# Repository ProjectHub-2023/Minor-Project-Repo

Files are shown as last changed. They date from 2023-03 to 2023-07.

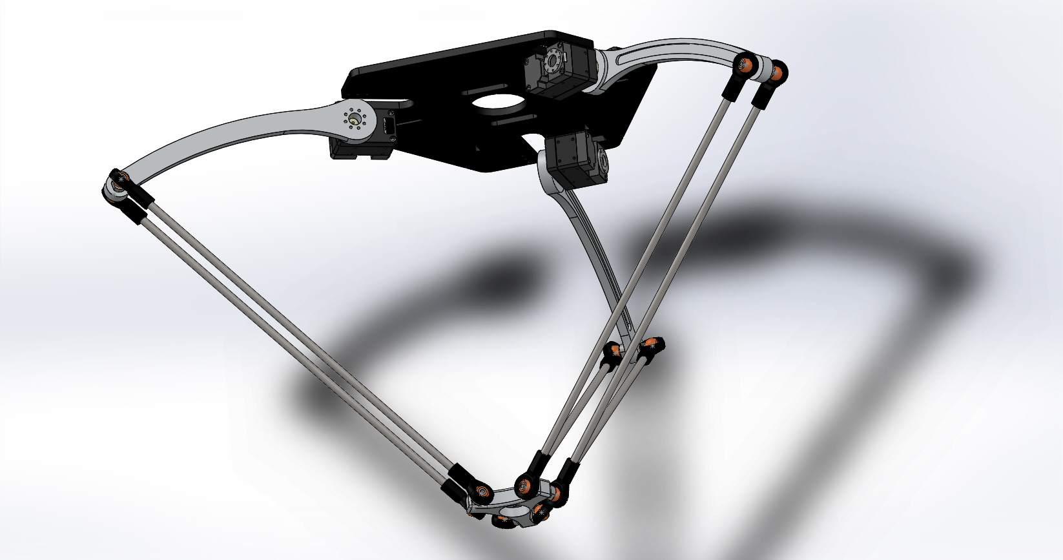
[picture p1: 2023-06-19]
3d_design/Mat_1.JPG

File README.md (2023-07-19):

# Quality Control of Products using 4-DOF Delta Robot

## Introduction

A Delta Robot is a type of parallel robotic manipulator known for its high-speed and precise motion capabilities. Unlike traditional serial robotic manipulators, which use a series of connected joints and links, Delta Robots employ a parallel mechanism with multiple arms connected to a common base. This design allows for greater agility, reduced inertia, and improved performance in high-speed applications, making them ideal for tasks that require rapid and accurate movements. The 4-DOF Delta Robot for Quality Control presented here harnesses these unique characteristics to carry out quality control operations efficiently.

## Problem Description
The problem is to develop a solution for pick and place operations in industrial settings using a delta robot. The objective is to create a system that can efficiently and accurately pick up objects from one location and place them in another, based on predefined parameters or instructions. The solution should be designed to handle various types of objects, sizes, and weights commonly found in industrial environments.

The system needs to be reliable, capable of operating for extended periods without significant downtime. It should also be versatile, allowing for easy adaptation to different production lines or processes. The solution should offer precise control and positioning, ensuring that objects are picked up and placed with high accuracy and repeatability.

Efficiency is a key requirement, as the solution should optimize the pick and place operations to minimize cycle times and increase overall productivity. It should be capable of handling a high volume of objects within a given time frame, while maintaining quality and safety standards.

Integration with existing manufacturing systems and equipment is crucial. The solution should be compatible with industry-standard protocols and interfaces, enabling seamless communication and coordination with other machinery or control systems. Additionally, the solution should be user-friendly, providing intuitive interfaces for operators to monitor and control the pick and place operations effectively.

## Problem Statement
Develop a Cost and Power-efficient 4-DOF Delta Robot which can be used for the inspection and quality control of QR Code Equipped Industrial packages by referring to required dimensions stored in the database model. The segregated packages need to be sent back for re-evaluation.
## Features and Capabilities
- 4 degrees of freedom (4-DOF)
- Precise and accurate performance for quality control operations
- Dimension-based item classification
- Payload capacity of 100 grams, allowing for versatility in handling different products

#### Capabilities
1. Autonomous Operation
 - Detecting the Product
 - Differentiate betweenfaulty and non-faulty
 - Determining the position of the product w.r.t the conveyer
 - Pick Product
 - Handle Product
 - Deliver Product
 - Intersystem Communication
 - Database Management
2. Safety
 - Pick Product Safely
 - Handle Product Safely
 - Place Product Safely
 - Facilitates emergency STOP feature
3. Standby Mode
4. Easy adaptability to newer environment
## Dependencies
1. **Book Reference:** "Practical Model-Based System Engineering" by Carlos Hernandez and Jose L. Fernandez. This book served as a valuable resource for adopting a systematic approach in our project. It guided us in identifying the project's needs and defining its capabilities. 
2. **MATLAB:** 
 - Simulink: The project utilizes Simulink, an extension of MATLAB, for system-level modeling and simulation of the Delta Robot's control system. Simulink diagrams are used to visualize the robot's behavior and test control strategies in a virtual environment.

 - Simscape: Simscape, a part of the MATLAB/Simulink ecosystem, is utilized to model the physical dynamics of the Delta Robot in a multi-domain simulation environment. It allows for the accurate representation of the robot's mechanical, electrical, and hydraulic components, enabling realistic simulation of the robot's motion and behavior.
 - System Composer: The project leverages System Composer, a powerful tool in the MATLAB/Simulink ecosystem, for modeling and analyzing the system architecture and requirements. System Composer helps us gain a comprehensive understanding of the Delta Robot's behavior, interactions between components, and supports our systematic approach to system engineering.
3. **SolidWorks:** A 3D computer-aided design (CAD) software used for mechanical and product design. SolidWorks was employed to create detailed models of the Delta Robot's physical components and analyze their mechanical behavior.
4. **Trossen Robotics Community Guide:** A valuable resource used for programming the Delta Robot. This guide provides essential information, code examples, and best practices for effectively controlling and integrating the Delta Robot into various applications.
5. Marginally Clever Rotary Delta Robot Forward/Inverse Kinematics Calculator
6. Proto G Engineering. “Simplified Delta Robot Kinematics Equations”, YouTube, Feb. 11, 2018[Video File]. Available: https://www.youtube.com/watch?v=FTRCwuAnr6o&t=57s&ab_channel=ProtoGEngineering
7. **Dynamixel Wizard 2.0:**  A software tool provided by Dynamixel for configuring and managing Dynamixel servos used in the Delta Robot. Dynamixel Wizard 2.0 allows for easy setup, calibration, and fine-tuning of the servos to achieve precise movements and control.

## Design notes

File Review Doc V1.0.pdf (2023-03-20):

# 1.Operational Scenarios:

Deployment or Adaptation Phase

1. System Configurations and calibrations
2. Configure the system according to the product being used.

Operation Phase

3. Product/item detected.
4. System Start.
5. Pick Product/item.
6. Translate the product/item.
7. Place the Product/item.
8. Return to home position.
9. Stand by.
10.Emergency Stop.

### 1.1 Description of Operational Scenarios

Deployment or Adaptation Phase | S1 System configuration and calibration
Preconditions | • The System should arrive at the destination of set up without any damages. • An empty space should be made available for the system set up. • The specified space should be a leveled surface. • The power supply should be available.
Triggering Event | The system should be bought by a customer.
Description | The system is bought by the customer and it is our duty to set up, configure and calibrate off-line for the customer.
Post-Conditions | The system is configured and calibrated.
Operational Scenario | S2 Configure new product
Preconditions | • The system should be well set up. • The system should be configured and calibrated. • The product to be sorted should be labelled with QR code
Triggering Event | Dimensional analysis of product.
Description | We add new products labelled with QR code, possibly of different sizes and configure the system with new products.
Post-Conditions | Now, the product is placed on the conveyor, and it can be detected by the system.

Operational Scenario | S3 Product/item Detected.
Preconditions | • The power supply should be available. • The robot should be configured and ready to use. • The product/item should be on the conveyor.
Triggering Event | The product placed on the conveyor is sensed and a signal is sent that the product has arrived.
Description | The product is detected and helps to activate the system.
Post-Conditions | • System is started.
Operational Scenario | S4 System Start.
Preconditions | • The power supply should be available. • The sensors should detect the product/item.
Triggering Event | Product/item is detected in the previous scenario.
Description | Initializes the operational parameters required to complete a single cycle process.
Post-Conditions | The QR code is scanned and is then matched with the prerequisite data available in the database.
Operational Scenario | S5 Pick Product/item.
Preconditions | • The product/item should be within reach of the delta robot. • The weight of the product should be within the range of the robot’s payload capacity. • The dimensions of the product shouldn’t be the same as those of the dimensions saved in the database.
Triggering Event | The dimensions of the product/item do not match the dimensions recorded in the database.
Description | In this process the Delta robot picks up the products/items which do not match the dimensions.
Post-Conditions | • The product/item is picked up by the end effector ready to be translated by the bot.
Operational Scenario | S6 Translate the product/item.
Preconditions | • The product/item should already be held by the grippers. • It needs to be ensured that the location where the product/item is to be relocated is empty/free.
Triggering Event | The defective product/item is detected and is already picked up by the Delta Robot.
Description | This is the stage in which the product/item is transported to another location (segregated) from the main production line.
Post-Conditions | • The translated product is ready to be placed.

Operational Scenario | S7 Place the Product/item.
Preconditions | • The product/item should already be translated to the desired place and ready to be placed.
Triggering Event | The Delta Robot has translated and reached the desired place where the defective piece can be placed/dropped.
Description | The Delta Robot has picked and translated (product/item) a certain distance from the main conveyer and is now ready to place the defective product/item on an empty surface.
Post-Conditions | • The defective product has now been segregated from the main conveyer. • The robot can then return to its home position.
Operational Scenario | S8 Return to home position.
Preconditions | • All the operations involved in the completion of a single process cycle must be completed. • Gripper should not have any product attached to it.
Triggering Event | Completion of a single operation cycle.
Description | This is the stage where the robot returns to its home position after completing one cycle of operation and is ready to execute the next.
Post-Conditions | • Robot returns to home position and proceeds to go in STANDBY state after a set duration.
Operational Scenario | S9 Stand by.
Preconditions | • There shouldn't be any products/items arriving on the conveyor for a certain duration of time. • Previous cycle should have been completed
Triggering Event | Set threshold time to go into standby mode is exceeded.
Description | The Home position is maintained.
Post-Conditions | The robot in standby mode is ready for actuation in case a product is detected.
Operational Scenario | S10 Emergency Stop.
Preconditions | • The system should be running.
Triggering Event | When the emergency switch is closed.
Description | In this scenario, irrespective of what process is running the whole system is forcefully turned off in real-time.
Post-Conditions | • The whole system operations are suspended. • The power supply to all the electrical components are cut-out.

### 1.2. Operational Needs from Operational Scenarios

S3 Product/item Detected:
- ON3_1: The system shall identify the product on the conveyor line and notify the subsequent processes about its arrival.
- ON3_2: The system shall be able to visually perceive and differentiate between a moving conveyor and an object on a moving conveyor.
- ON3_3: The response time must be instantaneous or as minimal as possible.
- ON3_4:

S4 System Start:
- ON4_1: The system shall indicate the beginning of the operation.
- ON4_2: The system shall transmit activation signals to all its subsystems.
- ON4_3: The system status shall be logged into the database for diagnostics in case of any contingency.
- ON4_4:

S5 Pick Product/item:
- ON5_1: The system shall be able to pick products of cylinder or box shape, with a maximum dimension of 5 cm^3 and a minimum dimension of 0.5 cm³
and a maximum
weight of 100 g.
- ON5_2: The system shall complete the pick task in less than 2 seconds. if there are no potential collisions while performing.
- ON5_3: The system shall pick the item safely as per ISO 14539:2000.
- ON5_4: The moving parts of the system shall not present any sharp edges,
and the robot arm and the gripper to handle the parts shall be lightweight.

S6 Translate the product/item:
- ON6_1: The system shall change its position and orientation without dropping/damaging the product in the gripper.
- ON6_2: The system shall translate to the required location with minimal deviation.
- ON6_3: The system shall finish the repositioning in under 2 seconds.
- ON6_4:

S7 Place the Product/item:
- ON7_1: The system shall place the products in the desired location (whether it’s a conveyor or box)
- ON7_2: The system shall place the product with not more than 0.05 mm of clearance between the product and the surface.
- ON7_3: The system shall ensure that the release of the gripper and the product being placed on the surface are nearly simultaneous.
- ON7_4: The system shall ensure that the entire operation takes not more than 1.5 seconds to complete and move on to the subsequent process.
- ON7_5: The system shall place the item safely as per ISO 14539:2000.

S8 Return to home position:
- ON8_1: The system shall return all actuators and the end effector back to a certain predetermined configuration (home configuration).
- ON8_2: The system shall ensure that no product is currently being held by the gripper, unless the emergency STOP function has been engaged.
- ON8_3:
- ON8_4:

S9 Stand by:
- ON9_1: The system shall hold the relative positioning and orientation of the actuators and the end effector in the predetermined ‘Home’ configuration unless indicated otherwise by any other process.
- ON9_2: the system shall release the actuators and end effector from the home configuration when an appropriate trigger event occurs in the system (i.e., a faulty product is identified on the main conveyor).
- ON9_3: The transition of actuator states from ‘home’ configuration to the required configuration shall happen almost instantaneously and shall not take more than 2 seconds.
- ON9_4:

S10 Emergency Stop:
- ON10_1: The system shall terminate all currently ongoing operations.
- ON10_2: The actuators and the end effector shall halt their current actuation processes and hold their current position and orientation so as to not cause further damage.
- ON10_3: The state of the system shall be logged into the system as well as indicated to the operator.
- ON10_4: There shall be minimal delay between the trigger input and the triggering of the appropriate response. This shall not take more than 1 second.

## 2. UML Charts

### 2.1. Use Case Diagram

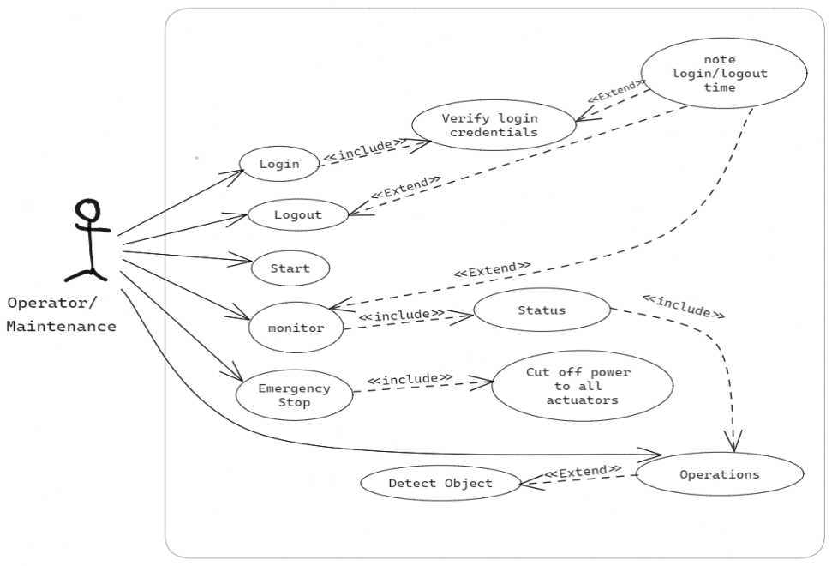
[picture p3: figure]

### 2.2. Sequence Diagram

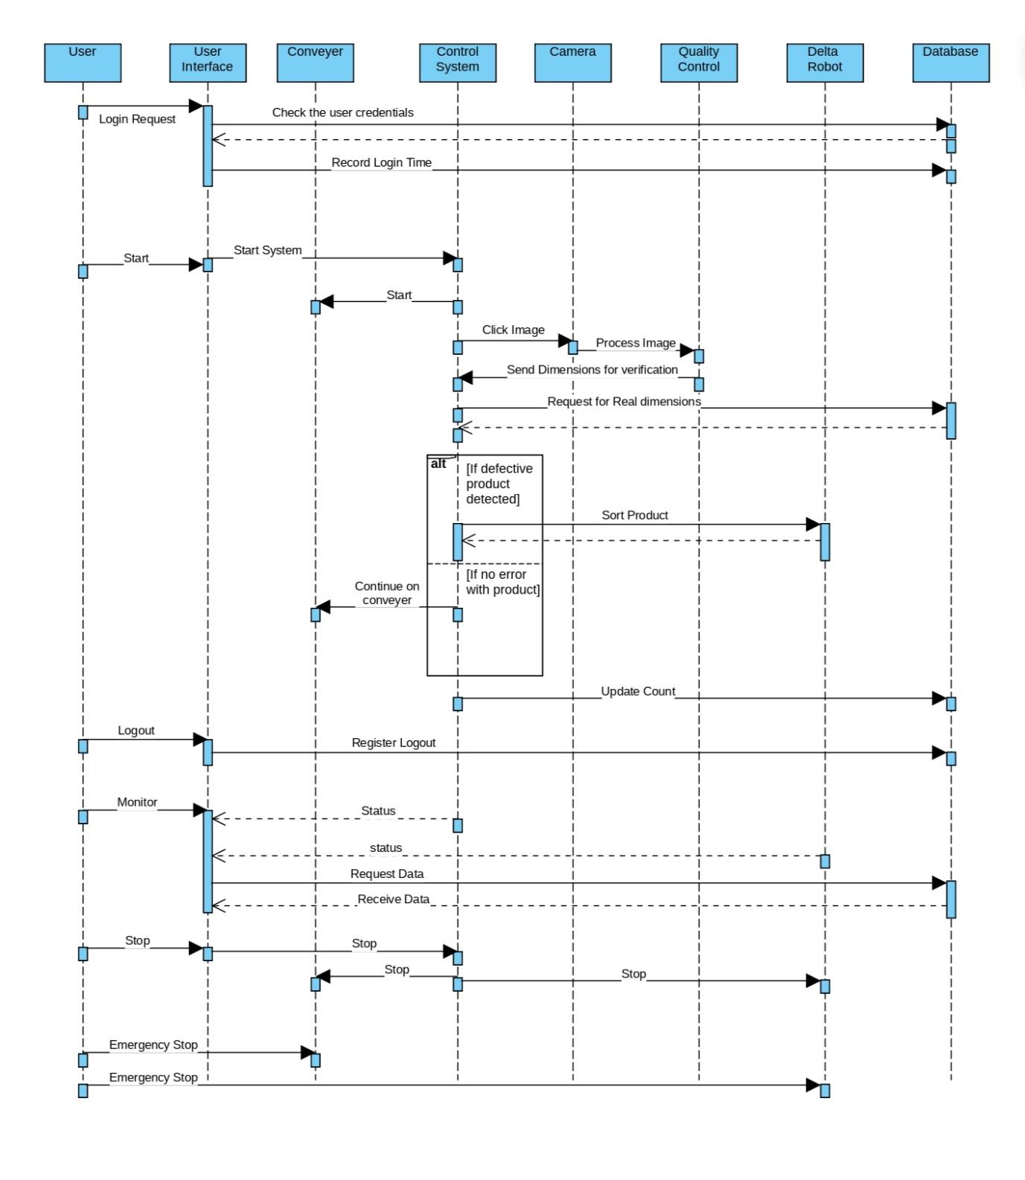
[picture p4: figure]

## 3. Capabilities

### 3.1. sysML Chart

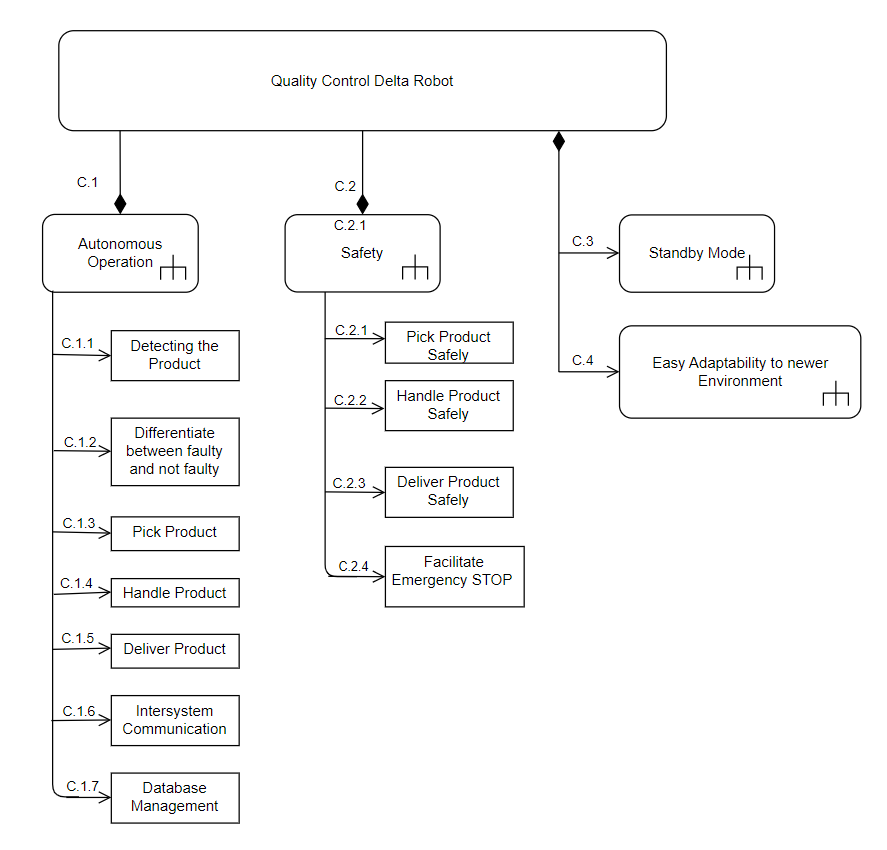
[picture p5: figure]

### 3.2. Capabilities

Capability | Description
C.1 Autonomous Operation | The robotic system should be able to identify and segregate faulty products from an ongoing production line autonomously.
C.1.1 Detecting the Product | The system should be able to detect the arrival of a product on a conveyer.
C.1.2 Differentiate between faulty and non-faulty | The system should be able to tell apart a faulty product from a conveyer line.
C.1.3 Determining the position of the product w.r.t the conveyer | The system should be able to determine the position of the product on the conveyer.

C.1.4 Pick Product | The robot can pick a product from the conveyer.
C.1.5 Handle Product | The robot can move holding any product without dropping it.
C.1.6 Deliver Product | The robot can deliver the products by placing them on to the desired location.
C.1.7 Intersystem Communication | The system should be able to communicate between the various subsystems so as to allow synchronization of processes.
C.1.8 Database Management | The system should have the ability to read, write and manipulate the database, whenever the need may arise.
C.2 Safety | The system and all its constituent subsystems must not cause harm to its surroundings with a priority to not cause any casualties to the operator.
C.2.1 Pick Product Safely | The robot picks the product while avoiding undesired collisions with any part of the product.
C.2.2 Handle Product Safely | The robot moves holding a product without losing grip on it or colliding with any obstacles.
C.2.3 Place Product Safely | The robot places the products in the desired location without inflicting any damage to the product.
C.2.4 Facilitates emergency STOP feature | In case of emergency, when indicated by the operator the system must terminate all operations instantaneously.
C.3 Standby Mode | After Initialisation or completion of an operation cycle, the system should have the ability to HOLD its position and wait for an appropriate trigger to begin operation.
C.4 Easy adaptability to newer environment | The system must be versatile enough to accommodate any work environment and operate optimally.

### 3.3 Traceability Matrix

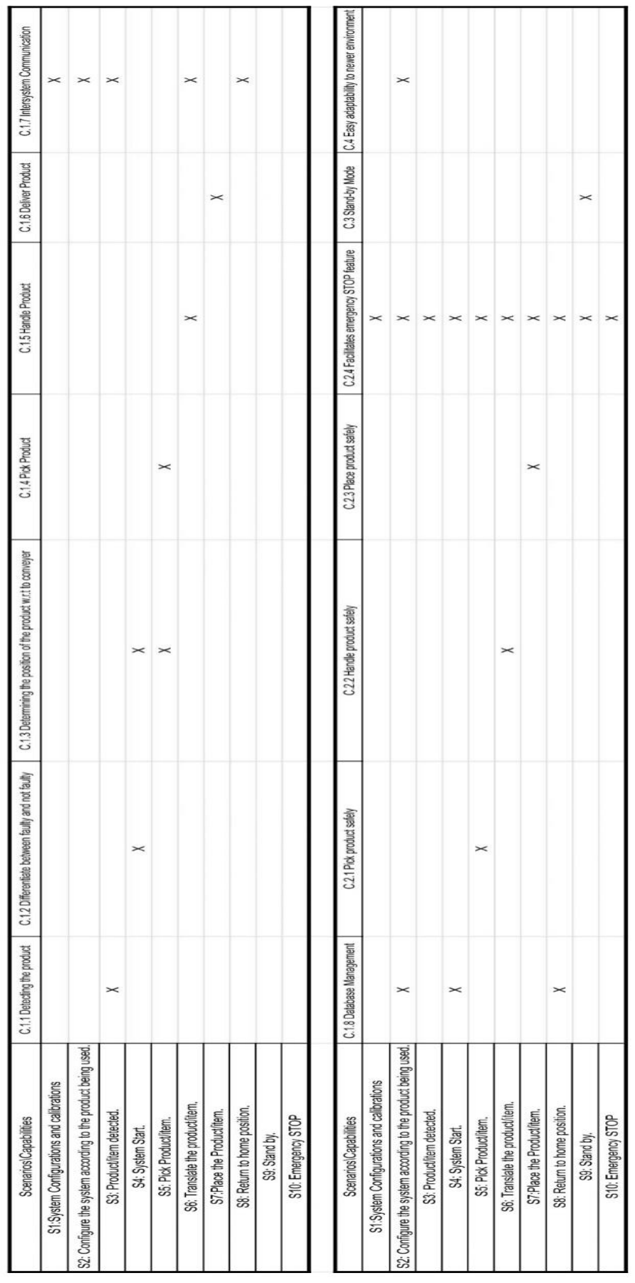
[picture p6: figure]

### 3.4 High Level Functions

High level Functions | Description
Manage Operation (From C1.1, C1.2, C3) | The system plans and executes the required operation based on the product categorisation.
Calibrate (from C4) | The system must be able to operate and adjust to different environments
Pick Product (from C1.4, C2.1, C2.2) | The system must pick the product in a safe manner without damaging the product.
Translate robot (from C2.2) | The system should translate the product without colliding with its operator or immediate environment.
Place Product (from C1.6, C2.2, C2.3) | The system places the product to the required location.
Handle Contingencies (from C2.4) | The system must stop all operations immediately when indicated by the user.

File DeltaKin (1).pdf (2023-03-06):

## The Delta Parallel Robot: Kinematics Solutions Robert L. Williams II, Ph.D., williar4@ohio.edu Mechanical Engineering, Ohio University, October 2016

Clavel’s Delta Robot¹
is arguably the most successful commercial parallel robot to date. The left image below shows the original design from Clavel’s U.S. patent² , and the right photograph below shows one commercial instantiation of the Delta Robot.

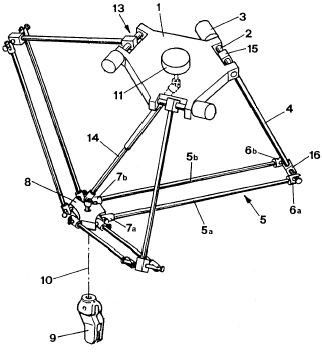
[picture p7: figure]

Delta Robot Design¹

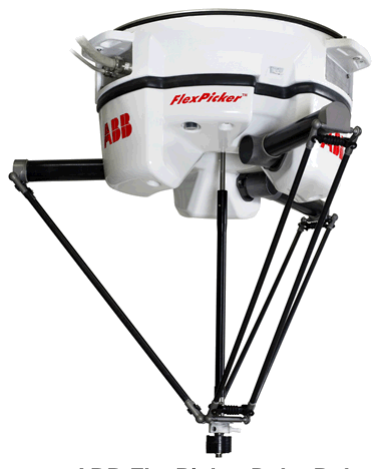
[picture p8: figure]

ABB FlexPicker Delta Robot www.abb.com

The Delta Robot has 4-degrees-of-freedom (dof), 3-dof for XYZ translation, plus a fourth inner leg to control a single rotational freedom at the end-effector platform (about the axis perpendicular to the platform). The remainder of this document will focus only on the 3-dof XYZ translation-only Delta Robot since that is being widely applied by 3D printers and Arduino hobbyists.

Presented is a description of the 3-dof Delta Robot, followed by kinematics analysis including analytical solutions for the inverse position kinematics problem and the forward position kinematics problem, and then examples for both, snapshots and trajectories. The velocity equations are also derived This is presented for both revolute-input and prismatic-input Delta Robots.

For referencing this document, please use:
R.L. Williams II, “The Delta Parallel Robot: Kinematics Solutions”, Internet Publication, www.ohio.edu/people/williar4/html/pdf/DeltaKin.pdf, January 2016.

1
R. Clavel, 1991, “Conception d'un robot parallèle rapide à 4 degrés de liberté”, Ph.D. Thesis, EPFL, Lausanne, Switzerland.
R. Clavel, 1990, “Device for the Movement and Positioning of an Element in Space”, U.S. Patent No. 4,976,582.

## Table of Contents

## Revolute-Input Delta Robot

Revolute-Input Delta Robot Description

As shown below, the 3-dof Delta Robot is composed of three identical RUU legs in parallel between the top fixed base and the bottom moving end-effector platform. The top revolute joints are actuated (indicated by the underbar) via base-fixed rotational actuators. Their control variables are
, | 1,2,3 i θ i = | about the axes shown. In this model θi are measured with the right hand, with zero angle
defined as when the actuated link is in the horizontal plane. The parallelogram 4-bar mechanisms of the three lower links ensure the translation-only motion. The universal (U) joints are implemented using three non-collocated revolute (R) joints (two parallel and one perpendicular, six places) as shown below.

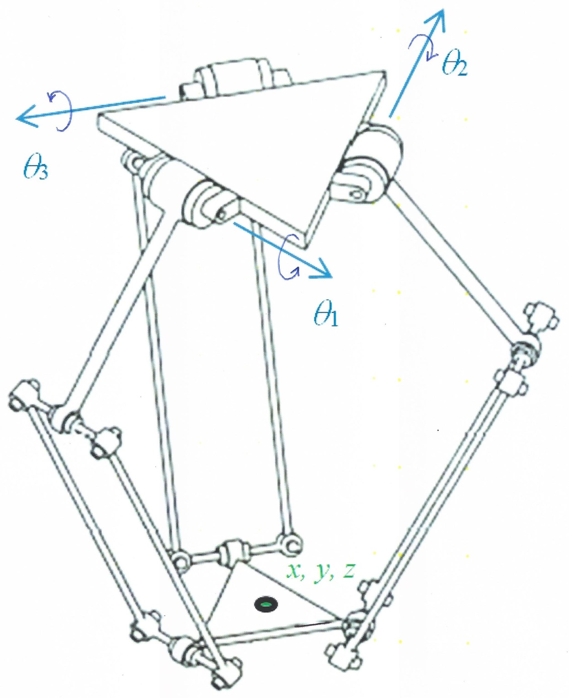
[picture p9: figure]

Delta Parallel Robot Diagram adapted from: elmomc.com/capabilities

The three-dof Delta Robot is capable of XYZ translational control of its moving platform within
its workspace. Viewing the three identical RUU chains as legs, points , | 1,2,3 Bi i | = | are the hips, points
, | 1,2,3 Ai i | = | are the knees, and points , | 1,2,3 Pi i | = | are the ankles. The side length of the base
equilateral triangle is sB and the side length of the moving platform equilateral triangle is sP. The moving platform equilateral triangle is inverted with respect to the base equilateral triangle as shown, in a constant orientation.

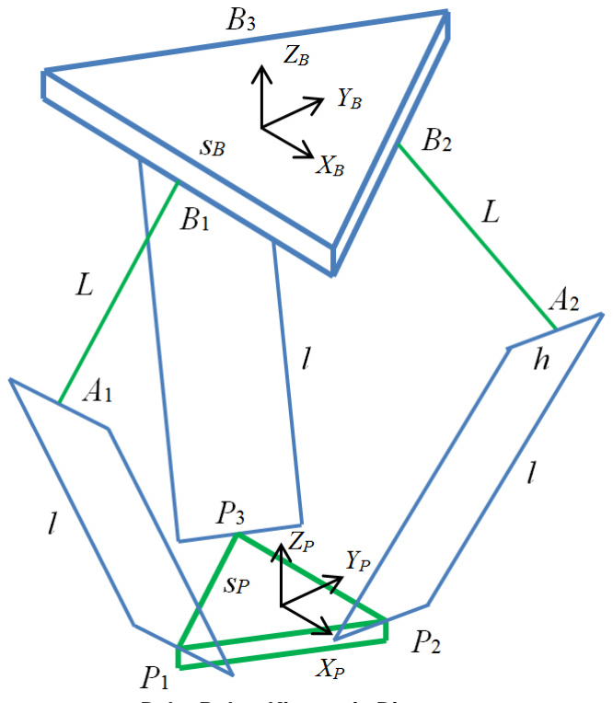
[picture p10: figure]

Delta Robot Kinematic Diagram

The fixed base Cartesian reference frame is {B}, whose origin is located in the center of the base equilateral triangle. The moving platform Cartesian reference frame is {P}, whose origin is located in the center of the platform equilateral triangle. The orientation of {P} is always identical to the orientation of {B} so rotation matrix 3

B

PRI = is constant. The joint variables are | { 1 | 2 | 3}
T

### Θ= θ θθ , and

the Cartesian variables are | { | } B | T
P P = x yz . The design shown has high symmetry, with three upper leg lengths L and three lower lengths l (the parallelogram four-bar mechanisms major lengths).

The Delta Robot fixed base and platform geometric details are shown on the next page.

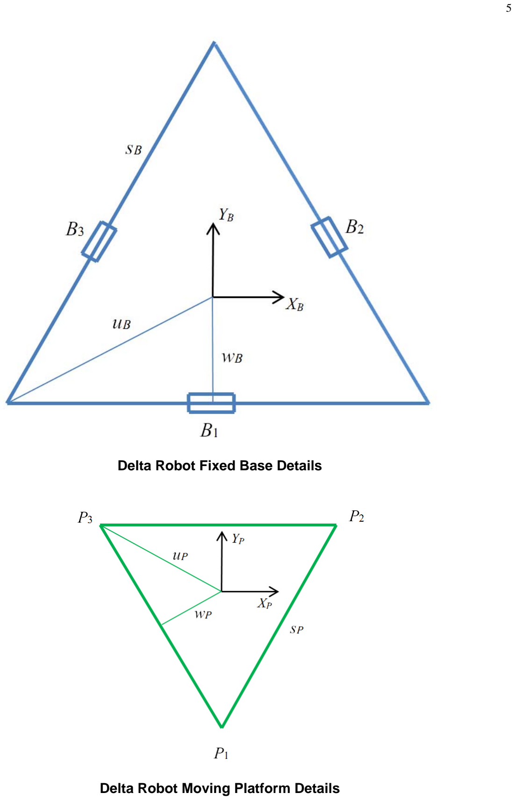
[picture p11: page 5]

Delta Robot Fixed Base Details

Delta Robot Moving Platform Details

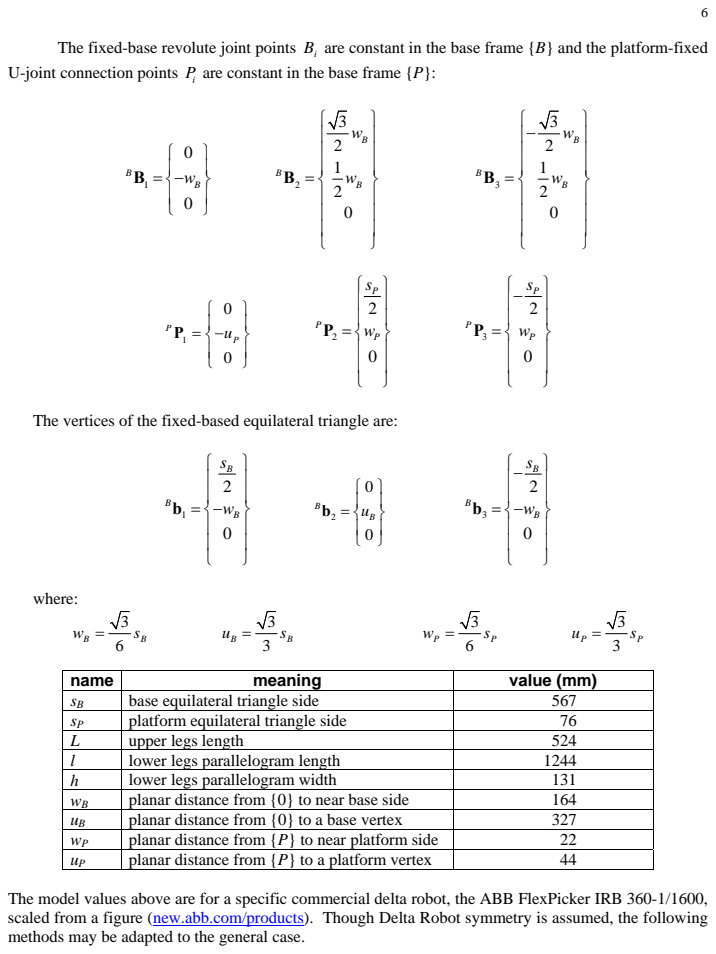
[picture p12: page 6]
where:

The fixed-base revolute joint points Bi are constant in the base frame {B} and the platform-fixed
U-joint connection points Pi are constant in the base frame {P}:

The vertices of the fixed-based equilateral triangle are:

name | meaning | value (mm)
sB | base equilateral triangle side | 567
sP | platform equilateral triangle side | 76
L | upper legs length | 524
l | lower legs parallelogram length | 1244
h | lower legs parallelogram width | 131
wB | planar distance from {0} to near base side | 164
uB | planar distance from {0} to a base vertex | 327
wP | planar distance from {P} to near platform side | 22
uP | planar distance from {P} to a platform vertex | 44

The model values above are for a specific commercial delta robot, the ABB FlexPicker IRB 360-1/1600,
scaled from a figure (new.abb.com/products). Though Delta Robot symmetry is assumed, the following
methods may be adapted to the general case.

Revolute-Input Delta Robot Mobility

This section proves that the mobility (the number of degrees-of-freedom) for the Delta robot is indeed 3-dof. Using the spatial Kutzbach mobility equation for the previous Delta Robot figure:

1 | 2 | 3 M = 6( | 1) 5 | 4 | 3 N | J | J | J -- | - | -

where:
M is the mobility, or number of degrees-of-freedom N is the total number of links, including ground
J1 is the number of one-dof joints
J2 is the number of two-dof joints
J3 is the number of three-dof joints

J1 – one-dof joints: revolute and prismatic joints J2 – two-dof joints: universal joint
J3 – three-dof joints: spherical joint

For the as-designed Delta Robot, we have:

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
6(17 1) 5(21) 4(0) 3(0)
9 dof

M
M
= | -- | - | -
=-

As often happens, the Kutzbach equation fails because the result must obviously be 3-dof. This result predicts the Delta is a severely overconstrained statically indeterminate structure, which is incorrect. The Kutzbach equation knows nothing about special geometry – in the Delta Robot case, there are three parallel four-bar mechanisms. The overall robot would work kinematically identically to the original Delta Robot if we removed one of the long parallel four-bar mechanism links, along with two revolute joints each. With this equivalent case, the Kutzbach equation yields:

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
6(14 1) 5(15) 4(0) 3(0)
3 dof

M
M
= | -- | - | -
=

which is correct. An alternative approach to calculating the Delta Robot mobility is by ignoring the three parallel four-bar mechanisms, replacing each with a single link instead. In this we must count a universal joint at either end of this virtual link. This approach follows the simplified Delta Robot naming convention 3-RUU. The Kutzbach equation for this case also succeeds:

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
6(8 1) 5(3) 4(6) 3(0)
3 dof

M
M
= | -- | - | -
=

Either of the second two approaches works. The author prefers the former since it is closer to the actual Delta Robot design.

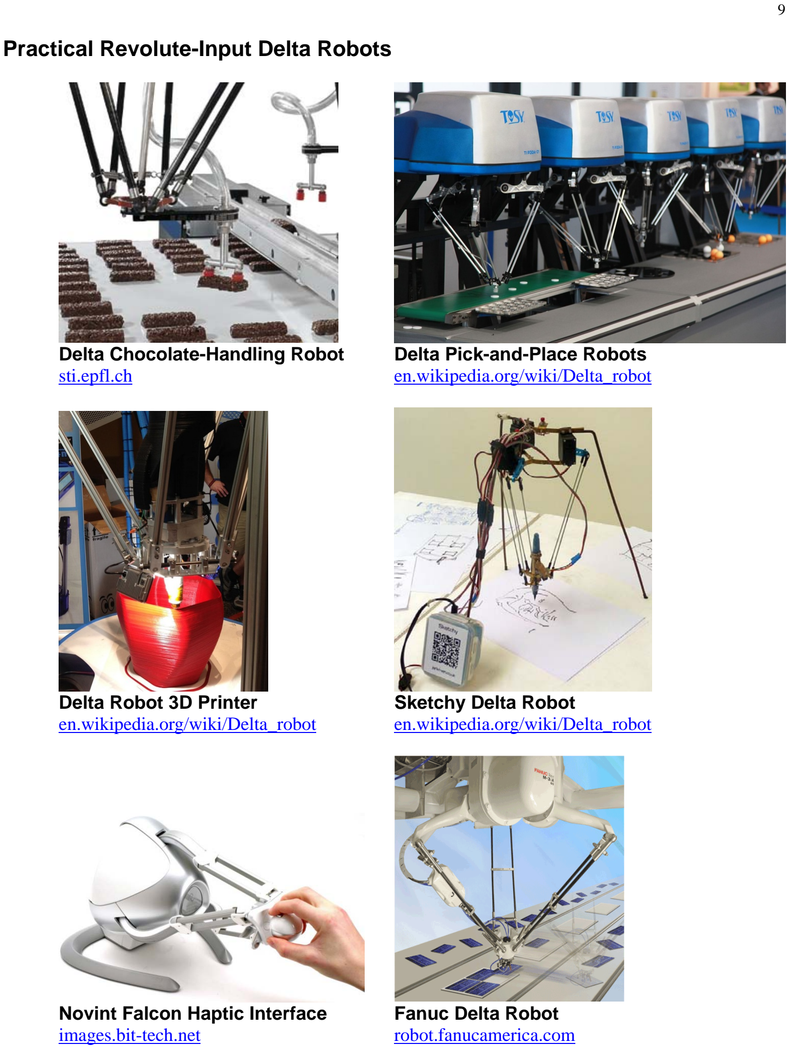
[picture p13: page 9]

Practical Revolute-Input Delta Robots

Delta Chocolate-Handling Robot | Delta Pick-and-Place Robots
sti.epfl.ch | en.wikipedia.org/wiki/Delta_robot
Delta Robot 3D Printer | Sketchy Delta Robot
en.wikipedia.org/wiki/Delta_robot | en.wikipedia.org/wiki/Delta_robot
Novint Falcon Haptic Interface | Fanuc Delta Robot
images.bit-tech.net | robot.fanucamerica.com

Revolute-Input Delta Robot Kinematics Analysis

From the kinematic diagram above, the following three vector-loop closure equations are written for the Delta Robot:
{ } { } { } { } | { } { } { } B | B | B | B | B | P | B | P
i | i | i | P | P | i | P | i + | + | = | + | = | + é | ù ë | û B | L | l | P | R | P | P | P | i =1,2,3
where | [ 3 ] B
P é | ù = ë | û R | I since no rotations are allowed by the Delta Robot.
The three applicable constraints state that the lower leg lengths must have the correct, constant length l (the virtual length through the center of each parallelogram):
{ } | { } { } { } { } B | B | P | B | B
i | i | P | i | i | i l = | = | + | - | - l | P | P | B | L | i =1,2,3

It will be more convenient to square both sides of the constraint equations above to avoid the square-root in the Euclidean norms:

{ } ² ² | 2 | 2 | 2 B
i | i | ix | iy | iz l | l | l | l = | =++ l | i =1,2,3
Again, the Cartesian variables are | { | } B | T
P P = x yz . The constant vector values for points Pi
and Bi | were given previously. | The vectors { } BLi | are dependent on the joint variables
{ 1 | 2 | 3}
T

### Θ= θ θθ :

1 | 1
| 1

0
cos
sin
B | L
L

θ
θ
ì | ü ï | ï =-í | ý
ï | ï î | þ -

L

2

2 | 2
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
ì | ü ï | ï ï | ï ï | ï = í | ý ï | ï ï - | ï ï | ï î | þ

L

3

3 | 3
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
ì | ü ï- | ï ï | ï ï | ï = í | ý ï | ï ï - | ï ï | ï î | þ

L

Substituting all above values into the vector-loop closure equations yields:

{}1 | 1

1

cos
sin

B

x
y L | a
zL

θ
θ
ì | ü ï | ï = | + | + í | ý
ï | ï î | þ +
l | {}

2

2 | 2
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
x | L | b
y | L | c
| zL

θ

θ
θ
ì | ü ï - | + ï ï | ï ï | ï = | - | + í | ý ï | ï ï | + | ï ï | ï î | þ
l | {}

3

3 | 3
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
x | L | b
y | L | c
| zL

θ

θ
θ
ì | ü
ï | ï + | -
= | - | + í | ý
ï | ï
+
î | þ

l

where: | 3
2 | 2
| 1
| 2
B | P

P
B
P | B

aw u
s b | w
cw | w
= | -

=-

= -

And the three constraint equations yield the kinematics equations for the Delta Robot:

2 | 2 | 2 | 2 | 2 | 2
1 | 1
2 | 2 | 2 | 2 | 2 | 2 | 2
2 | 2
2 | 2 | 2 | 2 | 2 | 2 | 2
3 | 3
2 ( | ) cos | 2 sin | 2 | 0
( 3( | ) | )cos | 2 sin | 2 | 2 | 0
( 3( | ) | )cos | 2 sin | 2 | 2 | 0
L y a | zL | x | y | z | a | L | ya l
L | x b | y c | zL | x | y | z | b | c | L | xb | yc l
L | x b | y c | zL | x | y | z | b | c | L | xb | yc l
θ | θ
θ | θ
θ | θ
+ | + | + + + + + + | -=
- | + ++ | + | + + + + + + + | + | - =
- -- | + | + + + + + + - | + | - =
The three absolute vector knee points are found using B | B | B A | B | L i | i | i = | + | , i =1,2,3:
1 | 1
| 1

0
cos
sin
B | wL B
L

θ
θ
ì | ü ï | ï =- - í | ý
ï | ï î | þ -

A

2

2 | 2

2

3 ( | cos ) 2
1 ( | cos )
2
sin

B

B
B
w | L
w | L

L

θ

θ
θ
ì | ü ï | + | ï ï | ï ï | ï = | + í | ý ï | ï ï | - | ï ï | ï î | þ

A

3

3 | 3

3

3 ( | cos ) 2
1 ( | cos )
2
sin

B

B
B
w | L
w | L

L

θ

θ
θ
ì | | ü
ï | ï - | +
= | + í | ý
ï | ï -
î | | þ

A

Inverse Position Kinematics (IPK) Solution

The 3-dof Delta Robot inverse position kinematics (IPK) problem is stated: Given the Cartesian
position of the moving platform control point (the origin of {P}), | { | } B | T
P P = x yz , calculate the three
required actuated revolute joint angles | { 1 | 2 | 3}
T
Θ= θ θθ . The IPK solution for parallel robots is often straightforward; the IPK solution for the Delta Robot is not trivial, but can be found analytically. Referring to the Delta Robot kinematic diagram above, the IPK problem can be solved independently for each of the three RUU legs. Geometrically, each leg IPK solution is the intersection between a known circle (radius L, centered on the base triangle R joint point B
Bi) and a known sphere (radius l, centered on the moving platform vertex P
Pi).

This solution may be done geometrically/trigonometrically. However, we will now accomplish this IPK solution analytically, using the three constraint equations applied to the vector loop-closure equations (derived previously). The three independent scalar IPK equations are of the form:

cos | sin | 0 E | F | G i | i | i | i | i θ + | += θ | i =1,2,3

where:

1

1
2 | 2 | 2 | 2 | 2 | 2
1

2( )
2
2
E | | Ly a
F | zL
G | x | y | z | a | L | ya l
= | +
=
=+++++ -

2

2
2 | 2 | 2 | 2 | 2 | 2 | 2
2
( 3( | ) | )
2
2( | )
E | L | xb | yc
F | zL
G | x | y | z | b | c | L | xb yc l
=- | + + +
=
= + +++++ | + | -

3

3
2 | 2 | 2 | 2 | 2 | 2 | 2
3
( 3( | ) | )
2
2( | )
E | L | xb yc
F | zL
G | x | y | z b c | L | xb yc l
= | - --
=
= + + + + + +- + | -
The equation | cos | sin | 0 E | F | G i | i | i | i | i θ + | += θ | appears a lot in robot and mechanism kinematics and is readily
solved using the Tangent Half-Angle Substitution.

If we define tan
2

i
i t
θ = | then

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
θ | - = +
and | 2

2 sin
1

i
i
i

t
t

θ = +

Substitute the Tangent Half-Angle Substitution into the EFG equation: 2

2 | 2
1 | 2 | 0
1 | 1
i | i
i | i | i
i | i
t | t E | F | G
t | t
æ | ö | æ | ö - ç | ÷ | ç | ÷ + | +=
è | ø | è | ø + | + | 2 | 2 (1 | ) | (2 ) | (1 | ) 0 E | t | Ft | G | t i | i | i | i | i | i - + | + | +=
2 ( | ) | (2 ) | ( | ) 0 G Et | Ft | G E i | ii | ii | i | i - | + | + | + | = | quadratic formula: 1,2
2 | 2 | 2
i | i | i | i
i
i | i
F | E | F | G
t
GE
-± | + | - = | -

Solve for θi by inverting the original Tangent Half-Angle Substitution definition:

1 2tan ( ) i | i θ | t - =

Two θi solutions result from the ± in the quadratic formula. Both are correct since there are two valid solutions – knee left and knee right. This yields two IPK branch solutions for each leg of the Delta Robot, for a total of 8 possible valid solutions. Generally the one solution with all knees kinked out instead of in will be chosen.

Forward Position Kinematics (FPK) Solution

The 3-dof Delta Robot forward position kinematics (FPK) problem is stated: Given the three
actuated joint angles | { 1 | 2 | 3}
T
Θ= θ θθ , calculate the resulting Cartesian position of the moving platform
control point (the origin of {P}), | { | } B | T
P P = x yz . The FPK solution for parallel robots is generally very difficult. It requires the solution of multiple coupled nonlinear algebraic equations, from the three constraint equations applied to the vector loop-closure equations (derived previously). Multiple valid solutions generally result.

Thanks to the translation-only motion of the 3-dof Delta Robot, there is a straightforward
analytical solution for which the correct solution set is easily chosen. Since | { 1 | 2 | 3}
T
Θ= θ θθ are given,
we calculate the three absolute vector knee points using B | B | B A | B | L i | i | i = | + | , i =1,2,3. Referring to the
Delta Robot FPK diagram below, since we know that the moving platform orientation is constant,
always horizontal with | [ 3 ] B
P éù = ëû R | I , we define three virtual sphere centers B | B | P A | A | P iv | i | i = | - , i =1,2,3:
1 | 1
| 1

0
cos
sin

B
v | B | P wL | u
L

θ
θ
ì | ü ï | ï =- - | + í | ý
ï | ï î | þ -

A

2

2 | 2
| 2
3 ( | cos ) 2 | 2
1 ( | cos )
2
sin

P
B

B
v | B | P

s wL

wL | w

L

θ

θ
θ
ì | ü
ï | ï + | -
= | + | - í | ý
ï | ï -
î | þ

A

3

3 | 3
| 3
3 ( | cos ) 2 | 2
1 ( | cos )
2
sin

P
B

B
v | B | P

s wL

wL | w

L

θ

θ
θ
ì | ü ï- | + | + ï ï | ï ï | ï = | + | - í | ý ï | ï ï | - | ï ï | ï î | þ

A

and then the Delta Robot FPK solution is the intersection point of three known spheres. Let a sphere be referred as a vector center point {c} and scalar radius r, ({c}, r). Therefore, the FPK unknown point
{ } B PP | is the intersection of the three known spheres:
({ 1 } BA v , l) | ({ 2 } B
A v , l) | ({ 3 } B
A v , l).

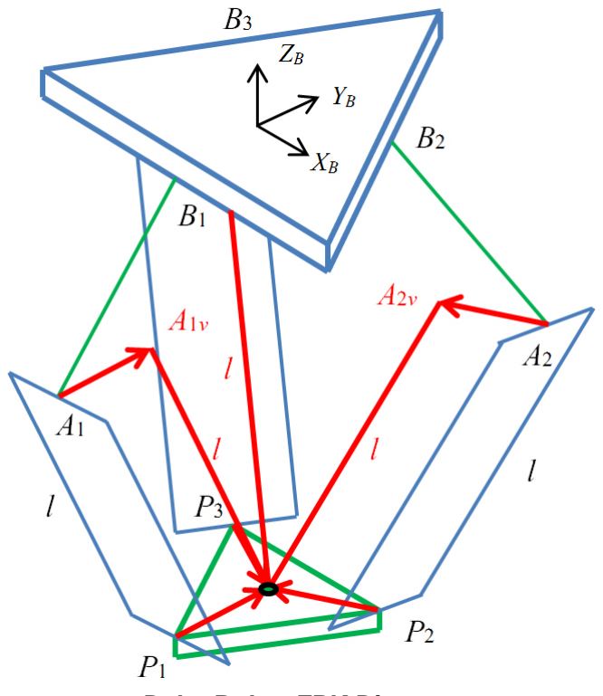
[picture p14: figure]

Delta Robot FPK Diagram

Appendix A presents an analytical solution for the intersection point of the three given spheres, from Williams et al.³
This solution also requires the solving of coupled transcendental equations. The appendix presents the equations and analytical solution methods, and then discusses imaginary solutions, singularities, and multiple solutions that can plague the algorithm, but all turn out to be no problem in this design.

In particular, with this existing three-spheres-intersection algorithm, if all three given sphere centers { } BAiv have the same Z height (a common case for the Delta Robot), there will be an

algorithmic singularity preventing a successful solution (dividing by zero). One way to fix this problem is to simple rotate coordinates so all { } BAiv Z values are no longer the same, taking care to reverse this

coordinate transformation after the solution is accomplished. However, we present another solution (Appendix B) for the intersection of three spheres assuming that all three sphere Z heights are identical, to be used in place of the primary solution when necessary.

Another applicable problem to be addressed is that the intersection of three spheres yields two solutions in general (only one solution if the spheres meet tangentially, and zero solutions if the center distance is too great for the given sphere radii l – in this latter case the solution is imaginary and the input data is not consistent with Delta Robot assembly). The spheres-intersection algorithm calculates both solution sets and it is possible to automatically make the computer choose the correct solution by ensuring it is below the base triangle rather than above it.

This three-spheres-intersection approach to the FPK for the Delta Robot yields results identical
to solving the three kinematics equations for | { | } B | T
P P = x yz given | { 1 | 2 | 3}
T
Θ= θ θθ .

3 R.L. Williams II, J.S. Albus, and R.V. Bostelman, 2004, “3D Cable-Based Cartesian Metrology System”, Journal of Robotic Systems, 21(5): 237-257.

Revolute-Input Delta Robot Velocity Kinematics Equations

The revolute-input Delta Robot velocity kinematics equations come from the first time derivative of the three position constraint equations presented earlier:

1 | 1 | 1 | 1 | 1 | 1
2 | 2 | 2 | 2 | 2 | 2
3 | 3 | 3 | 3
2 cos | 2 ( | ) sin | 2 sin | 2 | cos | 2 | 2( | ) | 2 | 0
( 3 | )cos | ( 3( | ) | ) sin | 2 sin | 2 | cos | 2( | ) | 2( | ) | 2 | 0
( 3 | )cos | ( 3( | ) | ) sin | 2 sin | 2
Ly | L y a | Lz | Lz | xx | y a y | zz
L | x y | L | x b | y c | Lz | Lz | x b x | y c y | zz
L | x y | L | x b | y c | Lz
θ | θθ | θ | θ θ
θ | θθ | θ | θ | θ
θ | θθ | θ
- | + | + | + | + | + | + | + | =
- | + | + | + ++ | + | + | + | + | + | + | + | =
- | - | - -- | + | +
- | | 3 | 3 Lz | x b x | y c y | zz θ | θ cos | 2( | ) | 2( | ) | 2 | 0 + | - | + | + | + | = | | |

Re-written:

1 | 1 | 1 | 1 | 1 | 1
2 | 2 | 2 | 2 | 2 | 2
3 | 3
( | ) | cos | sin | ( | ) sin | cos
2( | ) | 2( | ) | ( 3 | )cos | 2 | 2 sin | ( 3( | ) | ) sin | 2 | cos
2( | ) | 2( | ) | ( 3 | )cos | 2 | 2 sin | ( 3( | )
xx | y a y Ly | zz Lz | L y a | Lz
x b x | y c y L | x y | zz | Lz | L | x b | y c | Lz
x b x | y c y L | x y | zz | Lz | L | x b | y
θ | θ | θθ | θ θ
θ | θ | θθ | θ | θ
θ | θ
++ | + | ++ | = | + | -
+ | + | + | - | + | + | + | =- | + + + | -
- | + | + | + | - | + | + | = | - --
- | | | | | 3 | 3 | 3 | 3 c | Lz ) sin | 2 | cos θ θ | θ | θ - |

Written in matrix-vector form:
[ ]{ } [ ]{ }
1 | 1 | 11 | 1
2 | 2 | 2 | 22 | 2
33 | 3 3 | 3 | 3
cos | sin | 0 | 0
2( | ) | 3 cos | 2( | ) | cos | 2( | sin ) | 0 | 0
2( | ) | 3 cos | 2( | ) | cos | 2( | sin ) | 0 | 0
x | yaL | zL | x | b
xb | L | yc L | zL | y | b
xb | L | yc L | zL | z | b
θ | θ | θ
θ | θ | θ | θ
θ | θ | θ | θ
é | ù ++ | + | ìü é | ù ì ü ê | ú ïï ê | ú ï ï ê | ú +- | +- | + | = í ý | íý ê | ú ï ï | ïï -+ | +- | + | ê | ú ë | û îþ ë | û îþ
A X=B | Θ

where:

11 | 1 | 1 [ | ]
22 | 2 | 2
33 | 3 | 3
( | )sin | cos
( 3( | ) | )sin | 2 cos
( 3( | ) | )sin | 2 cos
b | Lya | z
b | L | xb | yc | z
b | L | xb | yc | z
θ | θ
θ | θ
θ | θ
= | + | -
=- | + + + | + é | ù ë | û
= | - -- | - é | ù ë | û

Revolute-Input Delta Robot Position Kinematics Examples
For these examples, the Delta Robot dimensions are from the table given earlier for the ABB FlexPicker IRB 360-1/1600, sB = 0.567, sP = 0.076, L = 0.524, l = 1.244, and h = 0.131 (m).

Inverse Position Kinematics Examples
Snapshot Examples | Nominal Position. Given { } { | } 0 0 | 0.9 B | T
PP = | - | m, the calculated IPK
results are (the preferred kinked out solution):
{ 20.5 | 20.5 | 20.5 }
T
Θ =- | - | - | |
General Position. Given { } { | } 0.3 0.5 | 1.1 B | T
PP = | - | m, the calculated IPK results are (the preferred
kinked out solution):
{47.5 11.6 21.4 }
T
Θ = | - | |

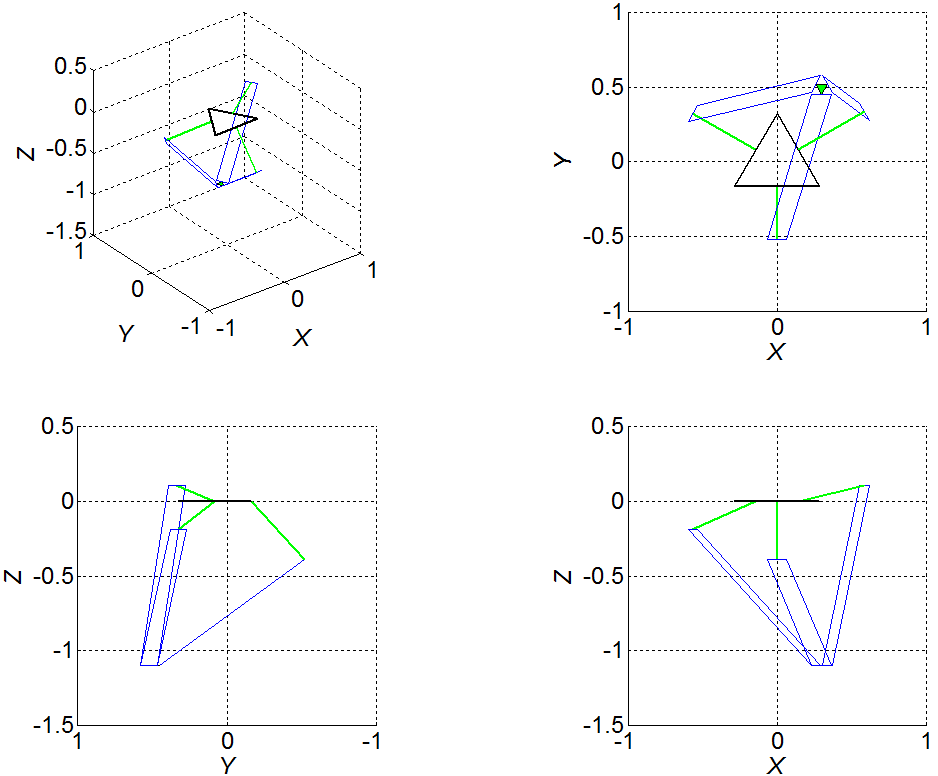
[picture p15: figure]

General Inverse Position Snapshot Example

IPK Trajectory Example

The moving platform control point {P} traces an XY circle of center { } 00 1 T
- m and radius 0.5
m. At the same time, the Z displacement goes through 2 complete sine wave motions centered on Z = -1 m with a 0.2 m amplitude.

This IPK trajectory, at the end of motion, is pictured along with the simulated Delta Parallel Robot, in the MATLAB graphics below.

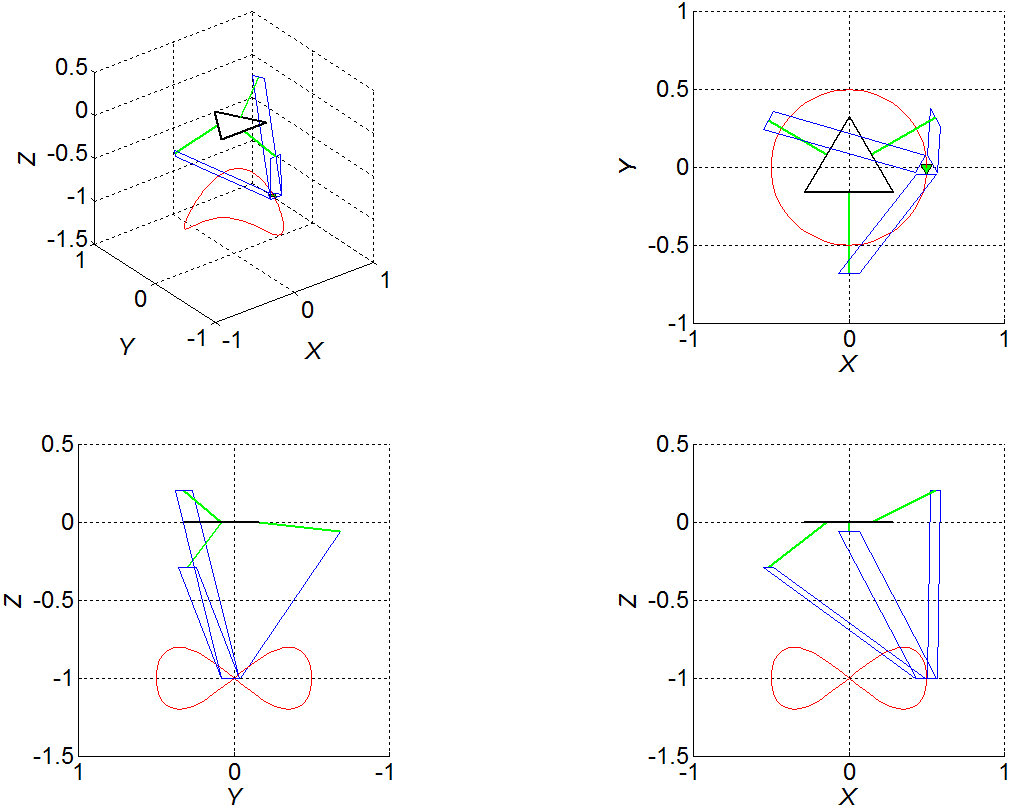
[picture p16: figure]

XY Circular Trajectory with Z sine wave

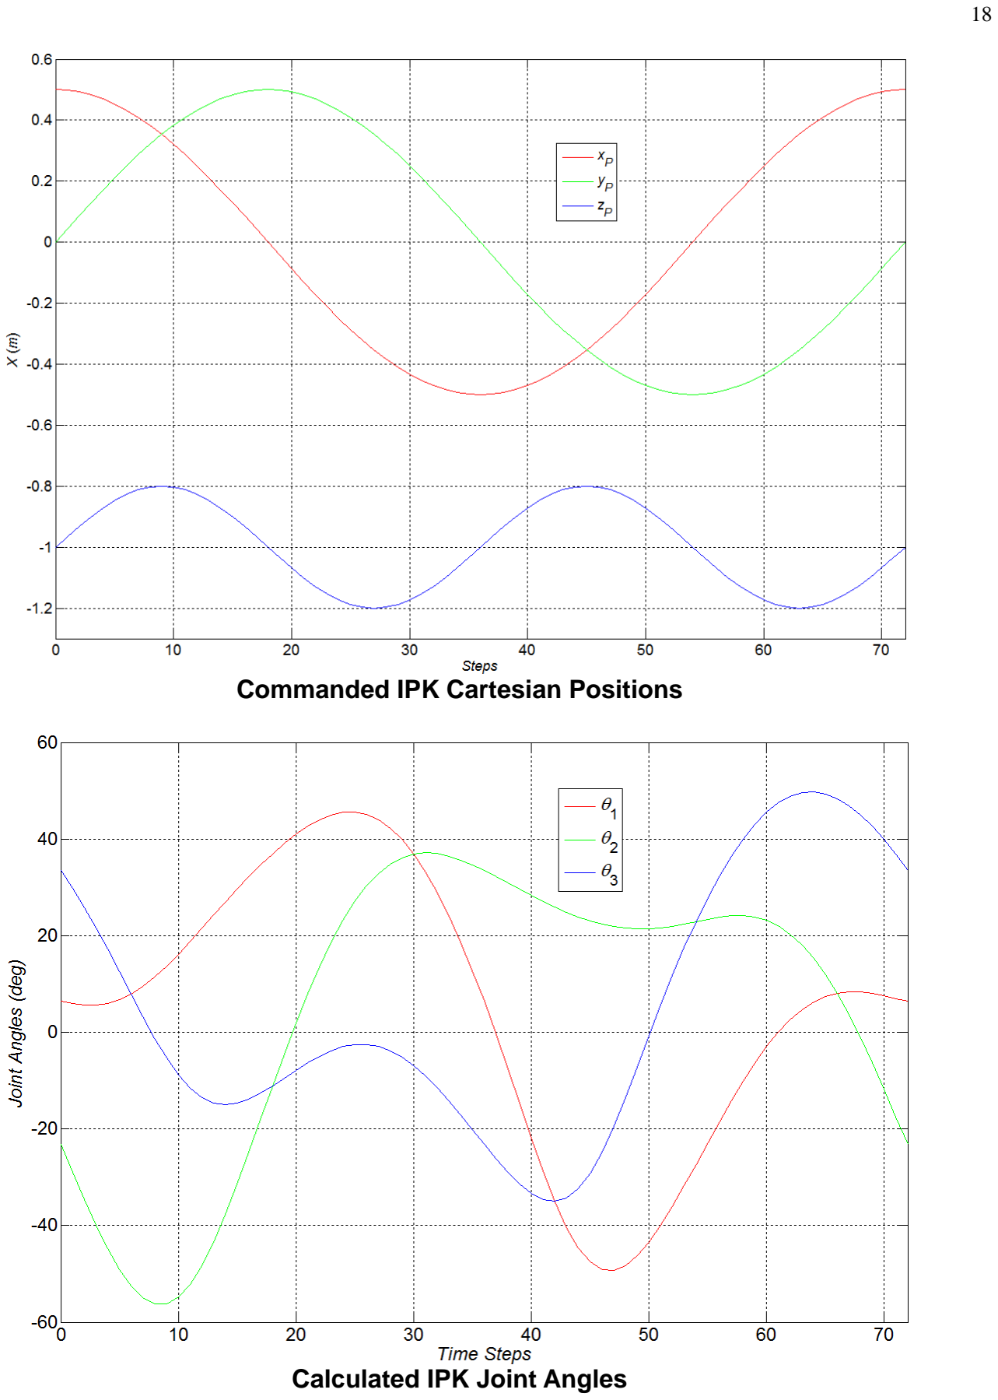
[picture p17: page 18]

Commanded IPK Cartesian Positions

Calculated IPK Joint Angles

Forward Position Kinematics Examples
Snapshot Examples | Nominal Position. Given | {000}
T
Θ= | , the calculated FPK results are
(the admissible solution below the base, using the equal-Z-heights spheres intersection algorithm):
{ } { | } 0 0 | 1.065 B | T
PP = | - | m
General Position. Given | {10 20 30 }
T
Θ = | | | m, the calculated FPK results are (the admissible
solution below the base, using the non-equal-Z-heights spheres intersection algorithm):
{ } { | } 0.108 | 0.180 | 1.244 B | T
PP = | - | - | m

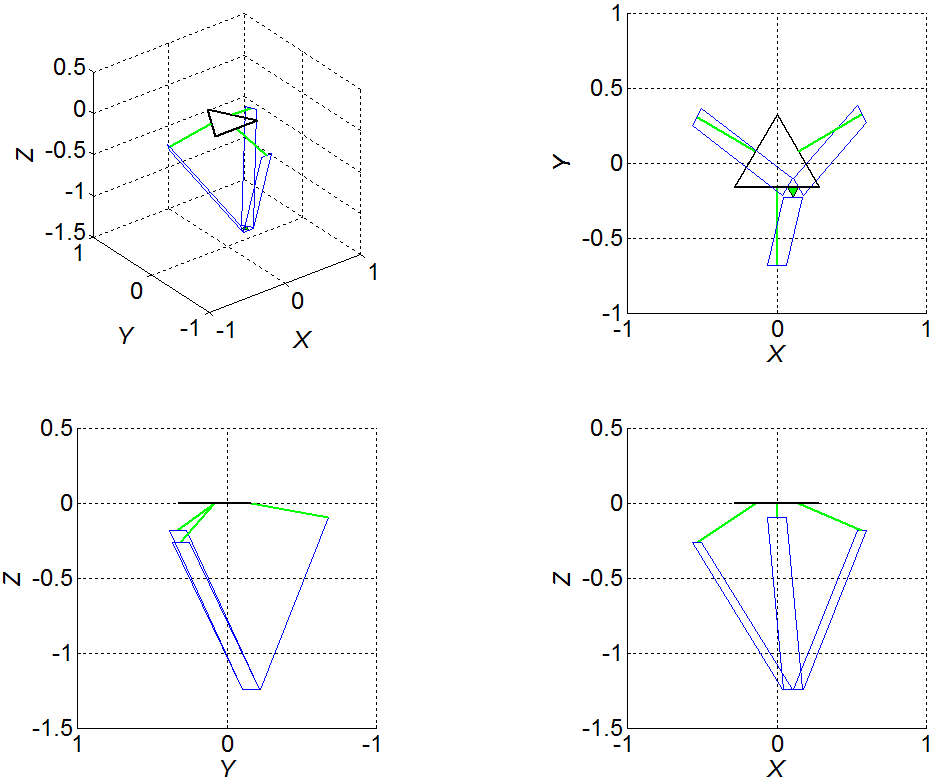
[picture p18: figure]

General Forward Position Snapshot Example

Circular Check Examples
All snapshot examples were reversed to show that the circular check validation works; i.e.: When
given { } { | } 0 0 | 1.065 B | T
PP = | - | , the IPK solution calculated | {000}
T
Θ= | and when given
{ } { | } 0.108 | 0.180 | 1.244 B | T
PP = | - | - | , the IPK solution calculated | {10 20 30 }
T
Θ = | | | . When given
{ 20.5 | 20.5 | 20.5 }
T
Θ =- | - | - | | | , the FPK solution calculated { } { | } 0 0 | 0.9 B | T
PP = | - | and when given
{47.5 | 11.6 21.4 }
T
Θ = | - | | | , the FPK solution calculated { } { | } 0.3 0.5 | 1.1 B | T
PP = | - | .

FPK Trajectory Example

The IPK solution is more useful for Delta Robot control, to specify where the tool should be in XYZ. This FPK trajectory example is just for demonstration purposes, not yielding any useful robot motion. Simultaneously the three revolute joint angles are commanded as follows:

1 | max
2 | max
3 | max
( ) | sin( )
( ) | sin(2 )
( ) | sin(3 )
t | t
t | t
t | t
θ | θ
θ | θ
θ | θ

=
=
=

where max θ = 45
and t proceeds from 0 to 2π in 100 steps. This closed FPK trajectory, at the end of motion, is pictured along with the simulated Delta Parallel Robot, in the MATLAB graphics below

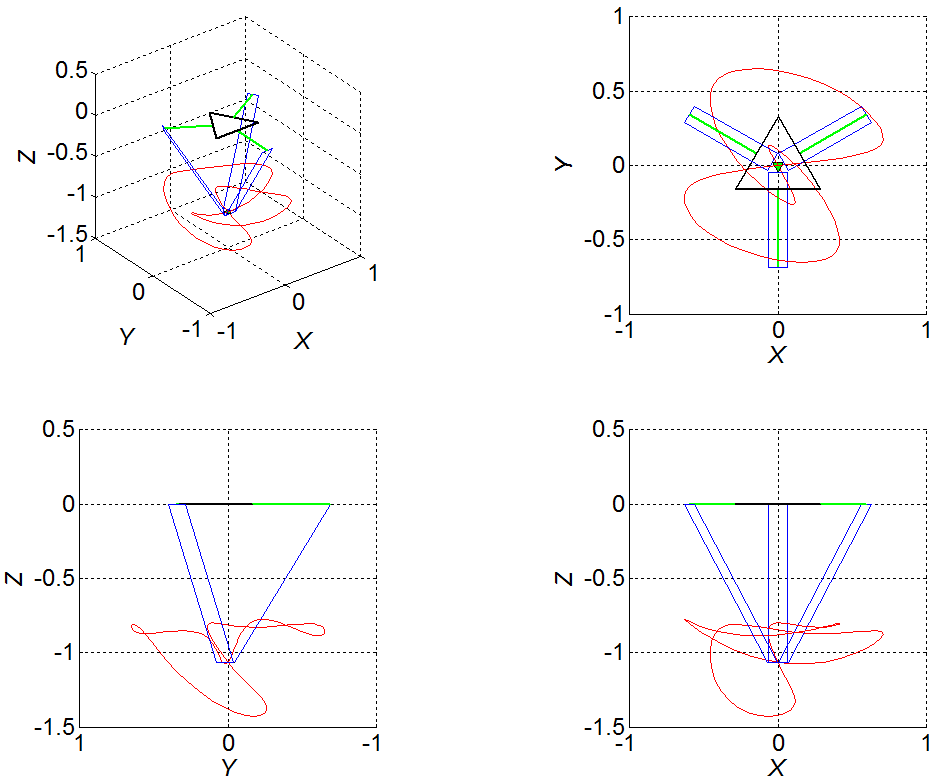
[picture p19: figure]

FPK Trajectory

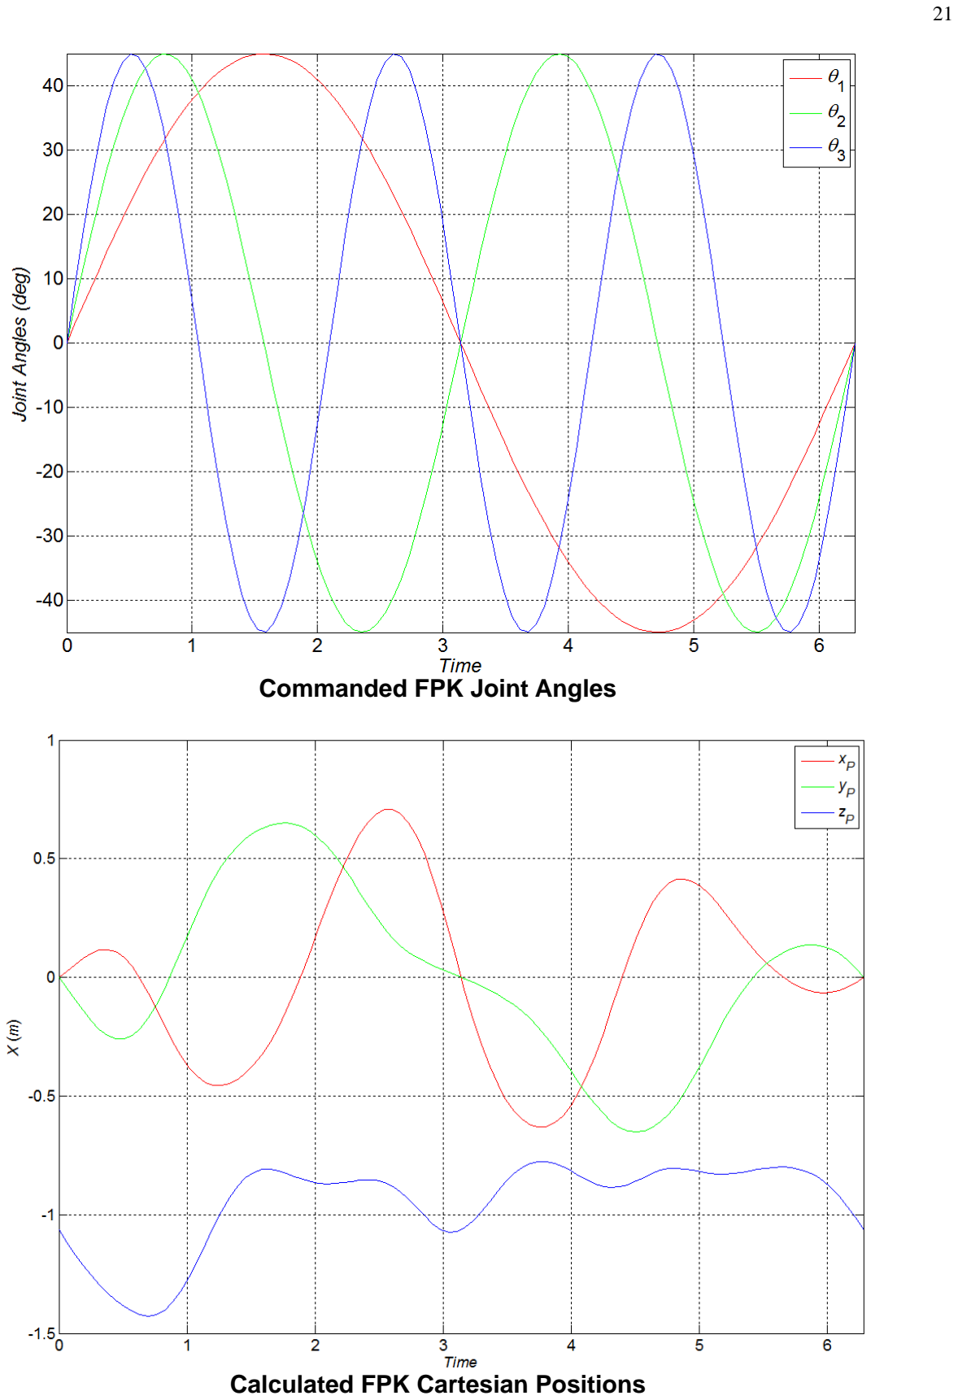
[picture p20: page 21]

Commanded FPK Joint Angles

Calculated FPK Cartesian Positions

## Prismatic-Input Delta Robot

Prismatic-Input Delta Robot Description

The Prismatic-Input Delta Robot is fundamentally similar to the original Revolute-Input Delta Robot. The major difference is that the three inputs now are driven by three linear-sliding prismatic joints instead of three revolute joints. This design change simplifies the kinematics equations and the IPK and FPK equations and solutions significantly, because the three prismatic inputs are aligned with the {B} frame Z axis, and there are no sines nor cosines required as in the revolute-input case.

As shown below, the 3-dof prismatic-input Delta Robot is composed of three identical PUU legs in parallel between the top fixed base and the bottom moving end-effector platform. The control
variables are , | 1,2,3 Li i | = | . In this model a positive change in Li is downward, in the -ZB direction.
The three-dof Delta Robot is again capable of XYZ translational control of its moving platform within its
workspace. The joint variables are | { 1 | 2 | 3}
T
L= L LL , and the Cartesian variables are | { | } B | T
P P = x yz .

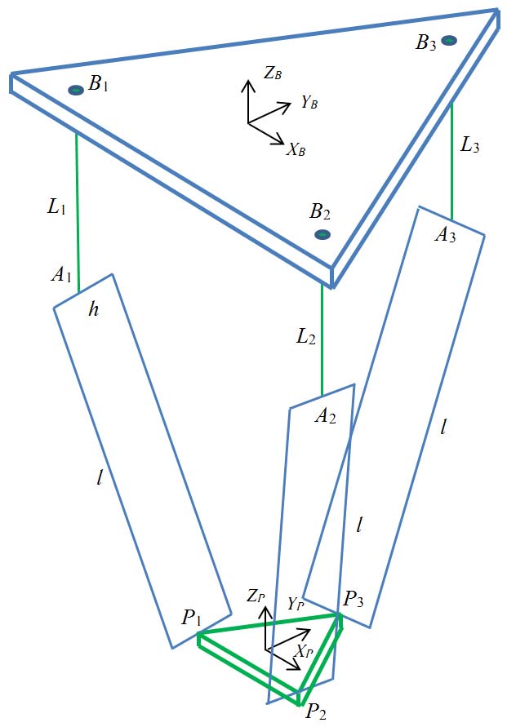
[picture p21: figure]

Delta Robot Kinematic Diagram – Prismatic Inputs

This robot is also known as the Linear Delta Robot or the Linear-Rail Delta Robot. The constant geometry (base points, platform vertices, etc.) presented earlier for the revolute-input Delta robot still apply to the prismatic-input Delta Robot. Also, the Mobility (dof) calculations for the prismatic-input case are identical to that presented for the revolute-input case, yielding M = 3. The Prismatic-Input Delta Robot fixed base and platform geometric details are shown on the next page.

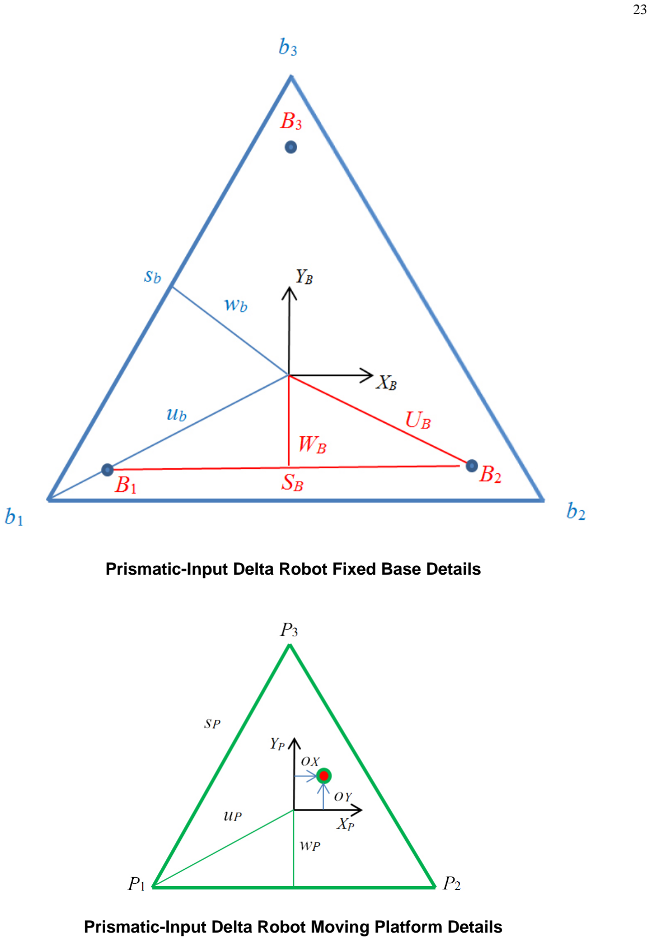
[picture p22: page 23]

Prismatic-Input Delta Robot Fixed Base Details

Prismatic-Input Delta Robot Moving Platform Details

The fixed-base prismatic joint points Bi are constant in the base frame {B} and the platform-fixed U-joint connection points Pi are constant in the base frame {P}. Both lie on the vertices of equilateral triangles, of sides SB and sP, respectively.

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
ì | | ü
-ï | ï
ï | ï =-í | ý
ï | | ï
ï | ï î | þ

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
ì | ü ï | ï ï | ï =-í | ý ï | ï ï | ï î | þ

B 3

0

0

P | UB

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
ì | ü ï | ï ï | ï =-í | ý ï | ï ï | ï î | þ

P 3

0

0

P
P u

ì ü ï ï = í ý ï ï îþ
P

The vertices of the fixed-based equilateral triangle are not directly used in the kinematics equations; they are used in MATLAB graphics for the support frame:

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
ì | | ü
-ï | | ï
ï | ï =-í | ý
ï | | ï
ï | ï î | þ
b | 2

2

0

b

B
b

s

w

ì | ü ï | ï ï | ï =-í | ý ï | ï ï | ï î | þ
b | 3

0

0

B
b u

ì ü ï ï = í ý ï ï îþ
b

where:

3
6
W | S B | B = | 3
3
U | S B | B = | 3
6
w | s b | b = | 3
3 b | b u | s =

3
6
w | s P | P = | 3
3 P | P u | s =

Prismatic-Input Delta Robot Parameters

name | meaning | value (mm)
sb | base equilateral triangle side | 432
wb | planar distance from {0} to near base side | 124.7
ub | planar distance from {0} to a base vertex | 249.4
H | frame height | 686
SB | P joints (Bi) equilateral triangle side | 246
WB | same as wb, for P joints equilateral triangle | 71
UB | same as ub, for P joints equilateral triangle | 142
sP | platform equilateral triangle side | 127
wP | planar distance from {P} to near platform side | 37
uP | planar distance from {P} to a platform vertex | 73
oX | nozzle X offset | 10
oY | nozzle Y offset | 30
Lmin | i = 1,2,3 minimum prismatic joints lengths | 67
Lmax | i = 1,2,3 maximum prismatic joints lengths | 479
l | lower legs parallelogram length | 264
h | lower legs parallelogram width | 44

The model values above are for a specific commercial prismatic-input delta robot 3D printer, the Delta Maker (deltamaker.com). Though Delta Robot symmetry is assumed, the following methods may be adapted to the general case for the prismatic-input delta robot.

Note that each individual prismatic length limits are 67 | 479 ≤ Li ≤ | mm; however, for all three
prismatic lengths equal, | 358 Li = | mm is the maximum extent to avoid motion through the 3D printing
surface.

Practical Prismatic-Input Delta Robots

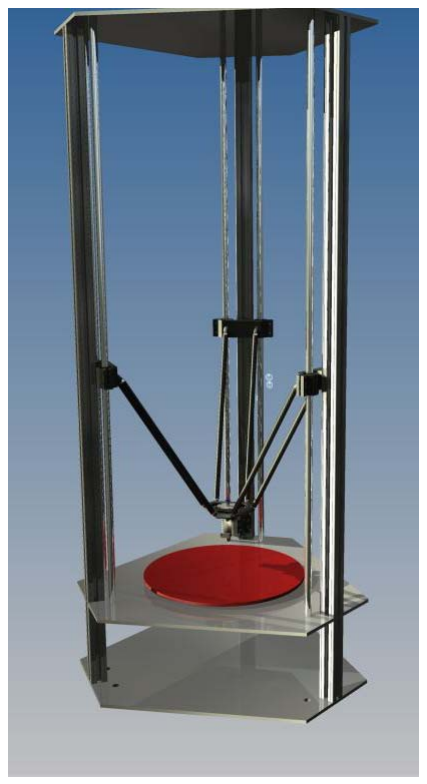
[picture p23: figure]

forums.reprap.org

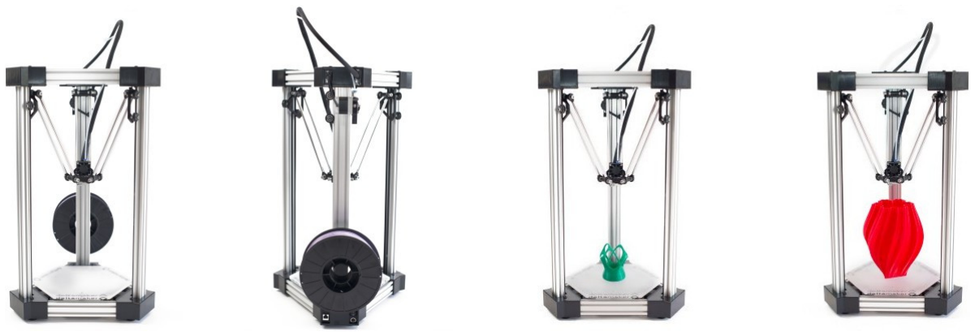
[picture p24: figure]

deltamaker.com

Prismatic-Input Delta Robot Kinematics Analysis

From the kinematic diagram above, the following three vector-loop closure equations are written for the Delta Robot:
{ } { } { } { } | { } { } { } B | B | B | B | B | P | B | P
i | i | i | P | P | i | P | i + | + | = | + | = | + é | ù ë | û B | L | l | P | R | P | P | P | i =1,2,3

The three applicable constraints state that the lower leg lengths must have the correct, constant length l (the virtual length through the center of each parallelogram):
{ } | { } { } { } { } B | B | P | B | B
i | i | P | i | i | i l = | = | + | - | - l | P | P | B | L | i =1,2,3

It will be more convenient to square both sides of the constraint equations above to avoid the square-root in the Euclidean norms:

{ } ² ² | 2 | 2 | 2 B
i | i | ix | iy | iz l | l | l | l = | =++ l | i =1,2,3
Again, the Cartesian variables are | { | } B | T
P P = x yz . The constant vector values for points Pi
and Bi | were given previously. | The vectors { } BLi | are dependent on the joint variables
{ 1 | 2 | 3}
T
L= L LL ; these formulas are much simpler than those for the rotational-input case presented earlier:

0
0 B
i
Li

ì ü ï ï = í ý ï ï îþ -
L i =1,2,3

Substituting all above values into the vector-loop closure equations yields:

{}1

1

B

x a
y b
zL
ì | ü + ï | ï = | + í | ý
ï | ï î | þ +
l | {}2

2

B

x a
y b
zL
ì - ü ï | ï = | + í | ý ï | ï î | þ +
l | {}3

3

B

x
y c
zL
ì | ü ï | ï = | + í | ý
ï | ï î | þ +

l

where:

2 | 2
B | P
B | P
P | B
S | s
a

bW w
cu U
= | -
= | -
=-

And the three constraint equations yield the kinematics equations for the prismatic-input Delta Robot:

2 | 2 | 2 | 2 | 2 | 2 | 2
1 | 1
2 | 2 | 2 | 2 | 2 | 2 | 2
2 | 2
2 | 2 | 2 | 2 | 2 | 2
3 | 3
2 | 2 | 2 | 0
2 | 2 | 2 | 0
| 2 | 2 | 0
x | y | z | a | b | ax | by | zL L l
x | y | z | a | b | ax | by | zL | L l
x | y | z | c | cy | zL L l
+ + + + + | + | + | + -=
+ + + + - | + | + | + -=
+ + ++ | + | + -=
The three absolute vector knee points are found using B | B | B A | B | L i | i | i = | + | , i =1,2,3:

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
ì | | | ü
-ï | | | ï
ï | ï =-í | ý
ï | ï - ï | ï î | þ

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
ì | ü ï | ï ï | ï =-í | ý ï | ï -ï | ï î | þ

A 3

3

0

B | UB
L
ì | ü ï | ï = í | ý ï | ï î | þ -
A

Inverse Position Kinematics (IPK) Solution

The 3-dof prismatic-input Delta Robot inverse position kinematics (IPK) problem is stated:
Given the Cartesian position of the moving platform control point (the origin of {P}), | { | } B | T
P P = x yz ,
calculate the three required actuated prismatic joint angles | { 1 | 2 | 3}
T
L= L LL . The IPK solution for the prismatic-input Delta Robot is much simpler than that for the revolute-input Delta robot presented earlier and is easily found analytically. Referring to the prismatic-input Delta Robot kinematic diagram above, the IPK problem can be solved independently for each of the three PUU legs. Geometrically, each leg IPK solution is the intersection between a vertical line of unknown length Li (passing through base point B

Bi) and a known sphere (radius l, centered on the moving platform vertex P
Pi).

This solution may be done geometrically/trigonometrically. However, we will now accomplish this IPK solution analytically, using the three constraint equations independently (derived previously). The three independent scalar IPK equations are quadratic equations of the form:

2 | 2 | 0 L | zL C i | i | i + | += | i =1,2,3

where:

2 | 2 | 2 | 2 | 2 | 2
1
2 | 2 | 2 | 2 | 2 | 2
2
2 | 2 | 2 | 2 | 2
3
2 | 2
2 | 2
2
C | x | y | z | a | b | ax | by l
C | x | y | z | a | b | ax | by l
C | x | y | z | c | cy l
=+++++ | + | -
=++++- | + | -
= + +++ | -

So we simply have three independent quadratic equations to solve for the prismatic-length inputs Li, for each leg independently, where Ai = 1, Bi = 2z, and the Ci are given above. The IPK solution simplifies quite nicely:

2 Li | i =- ± | - z | zC | i =1,2,3

Two Li solutions result from the ± in the quadratic formula. These solutions can be referred to as knee up and knee down for each leg. This yields two IPK branch solutions for each leg of the prismatic-input Delta Robot, for a total of 8 possible solutions. Generally the one overall solution with all knees up will be chosen.

When 2

i z C< , the solution for Li is imaginary. This case should never occur in theory since the prismatic joint can extend as far as needed to maintain a real solution for each leg. However, in practice, there are of course prismatic joint limits. When 2

i zC= , the two solution branches (knee up and knee down) have become the same solution.

The IPK input xyz is for the moving platform geometric center. When the desired control point is offset from the center (as in the case of many 3D printers), an initial transformation is required prior to implementing the IPK solution:

B | B | P | 1
P | N | N T | TT- é ù é ùé | ù = ë û ë ûë | û

where

100
010
001 0
000 1

X

P | Y
N

O
O
T
é | | ù
ê | | ú
ê | ú éù = ëû ê | ú
ê | ú ë | û

and

1

100
010
001 0
000 1

X

P | Y
N

O
O
T-
é | - ù ê | ú - ê | ú é | ù = ë | û ê | ú ê | ú ë | û

This is a very simple transformation since the prismatic-input Delta Robot allows only translational
motion, with | [] 3
B | B é ùé ù P | N R = | = R | I ë ûë û | . To save a lot of computations with 1s and 0s, simply subtract OX and
OY from the x and y components, respectively, of the given (xyz)N to obtain the IPK moving-platform-center input xyz. N stands for nozzle in a 3D printer. The z component is unchanged in this transformation.

Forward Position Kinematics (FPK) Solution

The 3-dof prismatic-input Delta Robot forward position kinematics (FPK) problem is stated:
Given the three actuated joint angles | { 1 | 2 | 3}
T
L= L LL , calculate the resulting Cartesian position of the
moving platform control point (the origin of {P}), | { | } B | T
P P = x yz . The FPK solution for parallel robots is generally very difficult. It requires the solution of multiple coupled nonlinear algebraic equations, from the three constraint equations applied to the vector loop-closure equations (derived previously). Multiple valid solutions generally result.

Thanks to the translation-only motion of the 3-dof Delta Robot, there is a straightforward
analytical solution for which the correct solution set is easily chosen. Since | { 1 | 2 | 3}
T
L= L LL | are
given, we calculate the three absolute vector knee points using B | B | B A | B | L i | i | i = | + | , i =1,2,3. Referring to
the prismatic-input Delta Robot FPK diagram below, since we know that the moving platform
orientation is constant, always horizontal with | [ 3] B
Péù= ëû RI , we define three virtual sphere centers
B | B | P A | A | P iv | i | i = | - , i =1,2,3:

1

1

| 2 | 2
| B | P

B
v | B | P
S | s

Ww
L
ì | | | ü
-+ ï | | | ï
ï | | | ï
=- + í | | | ý
ï | ï - ï | ï î | þ

A 2

2

| 2 | 2
| B | P

B
v | B | P
S | s

Ww
L
ì | ü - ï | ï ï | ï
=- + í | ý ï | ï - ï | ï î | þ
A 3

3

0

B
v | B | P U | u
L
ì | ü ï | ï = | - í | ý
ï | ï î | þ -

A

and then the prismatic-input Delta Robot FPK solution is the intersection point of three known spheres. Let a sphere be referred as a vector center point {c} and scalar radius r, ({c}, r). Therefore, the FPK unknown point { } B
PP | is the intersection of the three known spheres:
({ 1 } BA v , l) | ({ 2 } B
A v , l) | ({ 3 } B
A v , l).

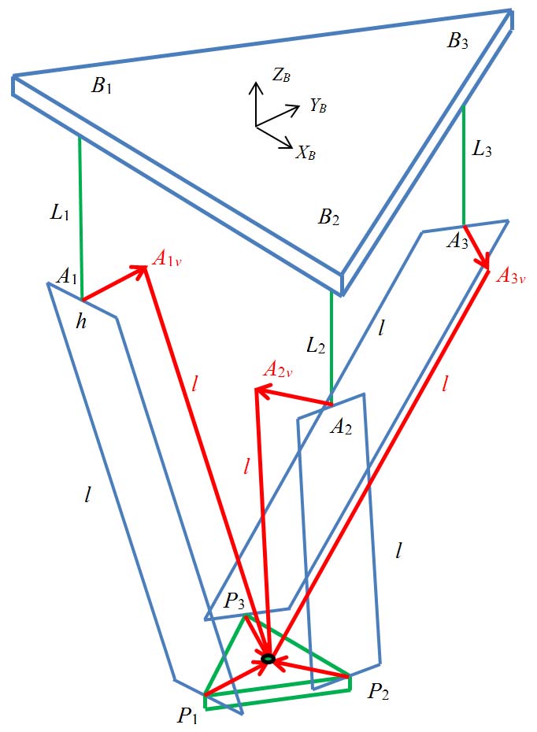
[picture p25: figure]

Delta Robot FPK Diagram – Prismatic Inputs

Appendix A presents an analytical solution for the intersection point of the three given spheres, from Williams et al.⁴
This solution also requires the solving of coupled transcendental equations. The appendix presents the equations and analytical solution methods, and then discusses imaginary solutions, singularities, and multiple solutions that can plague the algorithm, but all turn out to be no problem in this design.

In particular, with this existing three-spheres-intersection algorithm, if all three given sphere centers { } BAiv have the same Z height (a common case for the Delta Robot), there will be an

algorithmic singularity preventing a successful solution (dividing by zero). One way to fix this problem is to simple rotate coordinates so all { } BAiv Z values are no longer the same, taking care to reverse this

coordinate transformation after the solution is accomplished. However, we present another solution

4 R.L. Williams II, J.S. Albus, and R.V. Bostelman, 2004, “3D Cable-Based Cartesian Metrology System”, Journal of Robotic Systems, 21(5): 237-257.

(Appendix B) for the intersection of three spheres assuming that all three sphere Z heights are identical, to be used in place of the primary solution when necessary.

Another applicable problem to be addressed is that the intersection of three spheres yields two solutions in general (only one solution if the spheres meet tangentially, and zero solutions if the center distance is too great for the given sphere radii l – in this latter case the solution is imaginary and the input data is not consistent with prismatic-input Delta Robot assembly). The spheres-intersection algorithm calculates both solution sets and it is possible to automatically make the computer choose the correct solution by ensuring it is below the base triangle rather than above it.

The FPK solution xyz is for the moving platform geometric center. When the desired control point is offset from the center (as in the case of many 3D printers), a further transformation is required after to implementing the FPK solution:

B | B | P éN | P | N T | TT ù é ùé ù = ë û ë ûë û

where P éù NT ëû was given previously with the IPK solution. This is a very simple transformation since the
prismatic-input Delta Robot allows only translational motion, with | [] 3
B | B é ùé ù P | N R = | = R | I ë ûë û | . To save a lot of
computations with 1s and 0s, simply add OX and OY to the x and y components, respectively, of the FPK moving-platform-center solution xyz, to obtain the desired FPK solution (xyz)N. The z component is unchanged in this transformation.

Alternate FPK Solution

This three-spheres-intersection approach to the FPK for the prismatic-input Delta Robot yields
results identical to solving the three kinematics equations for | { | } B | T
P P = x yz given | { 1 | 2 | 3}
T
L= L LL .
Since the three constraint equations for the prismatic-input Delta Robot are much simpler than those for the revolute-input Delta Robot, we now present an alternative FPK analytical solution. The three constraint equations are repeated below:
2 | 2 | 2 | 2 | 2 | 2 | 2
1 | 1
2 | 2 | 2 | 2 | 2 | 2 | 2
2 | 2
2 | 2 | 2 | 2 | 2 | 2
3 | 3
2 | 2 | 2 | 0
2 | 2 | 2 | 0
| 2 | 2 | 0
x | y | z | a | b | ax | by | zL L l
x | y | z | a | b | ax | by | zL | L l
x | y | z | c | cy | zL L l
+ + + + + | + | + | + -=
+ + + + - | + | + | + -=
+ + ++ | + | + -=

Subtracting the second equation from the first equation yields a linear equation, expressing x as a function of z only:

x = f z dz e () =+

where:

2 1
2

L L d
a
- =
2 | 2
2 | 1
4

LL
e
a
- =

Further, subtracting the third equation from the first equation and substituting x = fz() from above yields another linear equation, expressing y as a function of z only:

y g z | Dz E = () = | +

where:
L3 1 L ad D
bc
-- = | -
2 | 2 | 2 | 2 | 2
3 | 1 2
2( | )
c | a b | ae L L E
bc
- -- | +- = | -

Substituting both x = fz() and y gz = () into the third equation yields a single equation in one unknown z, a quadratic polynomial:

2 Az Bz C + += 0

where:

2 2

3
2 | 2 | 2 | 2 | 2
| | | 3

1
2( | )
2
Ad | D
B | de DE cD L
C e E c | cE L l
=+ | +
= | + | + | +
=+ ++ | +-

And so the alternate analytical FPK solution is:

1,2

1,2 | 1,2 | 1,2
| 1,2 | 1,2 | 1,2
| | | 4
| | 2
| | ()
| | ()
B | B | AC
z
| | A
x | f z | dz | e
y | g z | Dz | E
-± | - =
= | = | +
= | = | +
There are two possible solution sets 1 | 1 | 1 (, ,) x yz and 2 | 2 | 2 (,,) x yz , due to the ± in the quadratic formula.
Generally only one solution will be used, the one where xyz is below the top-mounted base triangle.

Prismatic-Input Delta Robot Velocity Kinematics Equations

The prismatic-input Delta Robot velocity kinematics equations come from the first time derivative of the three position constraint equations presented earlier:

1 | 1 | 1
2 | 2 | 2
3 | 3 | 3
( | ) | ( | ) | ( | ) | ( | )
( | ) | ( | ) | ( | ) | ( | )
| | ( | ) | ( | ) | ( | )
x ax | y by | z L z | z L L
x ax | y by | z L z | z L L
xx | y cy | z L z | z L L
+ | + + | + + | =- +
- | + + | + + | =- +
| + + | + + | =- +

Written in matrix-vector form:
[ ]{ } [ ]{ }
1 | 1 | 1
2 | 2 | 2
3 | 3 | 3
0 | 0
0 | 0
0 | 0
x a yb zL | x | zL | L
x a ybzL | y | zL | L
x | yc zL | z | zL | L
é | ùì ü | é | ù + | + | + | + | ìü
ê | ú | ê | ú ïï | ïï - | + | + | =- | + í ý | íý ï ï | ïï ë | ûî þ | ë | û + | + | + | îþ
A X=B L |

The forward velocity solution is:
{ } [ ] [ ]{ } -1
X=A | B L |

And the inverse velocity solution is:
{ } [ ] [ ]{ } ¹
1 | 1
1

2
2 | 2
3
3 | 3

1

1

1

xa | yb
zL | zL L | x
xa | yb L | y zL | zL L | z
x | yc
zL | zL
=
é | ù + | + ê | ú + | + ìü | ì ü ïï | - | + | ï ï í ý | íý =- ê | ú + | + ï ï | ïï îþ | îþ +
ë | û + | +
L | B | AX |

Prismatic-Input Delta Robot Position Kinematics Examples
For these examples, the prismatic-input Delta Robot dimensions are from the table given earlier for the Delta Maker 3D Printer, sb = 0.432, SB = 0.246, sP = 0.127, l = 0.264, and h = 0.044 (m).

Inverse Position Kinematics Examples
Snapshot Examples | Nominal Position. Given { } {0 0 | 0.5} B | T
PP = | - | m, the calculated IPK
results are (the preferred lower solution):
{0.2451 0.2451 0.2451}
T
L= | m
General Position. Given { } {0.03 0.05 | 0.40} B | T
PP = | - | m, the calculated IPK results are (the preferred
kinked out solution):
{0.1664 0.1516 0.1384}
T
L= | m

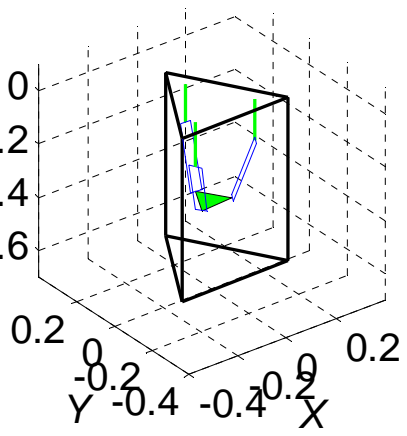
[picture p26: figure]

General Inverse Position Snapshot Example

-0.6

-0.4

-0.2
Z

0.2 0 -0.2 -0.4

-0.6

-0.4

-0.2

0

Y

Z

-0.4 -0.2 | 0 | 0.2 -0.4

-0.2

0

0.2

0.4

X

Y

-0.4 -0.2 | 0 | 0.2

-0.6

-0.4

-0.2

0

X

Z

T - m and radius

IPK Trajectory Example

The moving platform control point {P} traces an XY circle of center {0 0 0.5}
0.1 m. At the same time, the Z displacement goes through 2 complete sine wave motions centered on
Z =-1 m with a 0.05 m amplitude.

This IPK trajectory, at the end of motion, is pictured along with the simulated Delta Parallel
Robot, in the MATLAB graphics below.

XY Circular Trajectory with Z sine wave

Commanded IPK Cartesian Positions; Steps
Calculated IPK Joint Angles; Joint Lengths (m); Time Steps

Forward Position Kinematics Examples
Snapshot Examples | Nominal Position. Given | {0.2 0.2 0.2}
T
L= | m, the calculated FPK
results are (the admissible lower solution, using the equal-Z-heights spheres intersection algorithm):
{ } { | } 0 0 | 0.4549 B | T
PP = | - | m
General Position. Given | {0.14 0.15 0.16}
T
L= | m, the calculated FPK results are (the admissible
lower solution, using the non-equal-Z-heights spheres intersection algorithm):
{ } { | } 0.0215 | 0.0363 | 0.4012 B | T
PP =- | - | - | m

General Forward Position Snapshot Example

Circular Check Examples
All snapshot examples were reversed to show that the circular check validation works; i.e.:
When given { } { | } 0 0 | 0.4549 B | T
PP = | - | , the IPK solution calculated | {0.2 0.2 0.2}
T
L= | and when
given { } { | } 0.0215 | 0.0363 | 0.4012 B | T
PP =- | - | - | , the IPK solution calculated | {0.14 0.15 0.16}
T
L= | .
When given | {0.2451 0.2451 0.2451}
T
L= | , the FPK solution calculated { } {0 0 | 0.5} B | T
PP = | - | and
when given | {0.1664 0.1516 0.1384}
T
L= | , the FPK solution calculated { } {0.03 0.05 | 0.40} B | T
PP = | - | .

-0.4-0.20 0.2

-0.4 -0.2 0 0.2

-0.6

-0.4

-0.2

0

Y | X

Z

0.2 0 -0.2 -0.4

-0.6

-0.4

-0.2

0

Y

Z

-0.4 -0.2 | 0 | 0.2 -0.4

-0.2

0

0.2

0.4

X

Y

-0.4 -0.2 | 0 | 0.2

-0.6

-0.4

-0.2

0

X

Z

## Acknowledgements

This work was initiated during the last week of the author’s sabbatical from Ohio University at the University of Puerto Rico (UPR), Mayaguez, during Fall Semester 2014. The author gratefully acknowledges financial support from Ricky Valentin, UPR ME chair, and the Russ College of Engineering & Technology at Ohio University.

## Appendices

Appendix A. Three-Spheres Intersection Algorithm

We now derive the equations and solution for the intersection point of three given spheres. This solution is required in the forward pose kinematics solution for many cable-suspended robots and other parallel robots. Let us assume that the three given spheres are ( 1c ,r1), ( 2 c ,r2), and ( 3 c ,r3). That is,
center vectors | { | }T
x y z 1 = 1 | 1 | 1 c | , | { | }T
x | y | z 2 = 2 | 2 | 2 c | , | { | }T
x | y | z 3 = 3 | 3 | 3 c | , and radii r1, r2, and r3 are
known (The three sphere center vectors must be expressed in the same frame, {0} in this appendix; the answer will be in the same coordinate frame). The equations of the three spheres are:
( | ) ( | ) ( | )
( | )( | )( | )
( | )( | )( | ) | 2
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
x x | y y | z z | r
x x | y y | z z | r
x x | y y | z z | r
- | + - | + - | =
- | + - | + - | =
- | + - | + - | =
(A.1)

Equations (A.1) are three coupled nonlinear equations in the three unknowns x, y, and z. The
solution will yield the intersection point | { | }T P = x y z . The solution approach is to expand equations
(A.1) and combine them in ways so that we obtain x = f (y) and z = f (y); we then substitute these functions into one of the original sphere equations and obtain one quadratic equation in y only. This can be readily solved, yielding two y solutions. Then we again use x = f (y) and z = f () y to determine the remaining unknowns x and z, one for each y solution. Let us now derive this solution.

First, expand equations (A.1) by squaring all left side terms. Then subtract the third from the first and the third from the second equations, yielding (notice this eliminates the squares of the unknowns):

11 | 12 | 13 | 1 a x + a y + a z = b | (A.2)
21 | 22 | 23 | 2 a x +a y + a z = b | (A.3)

where:
( | )
( | )
( | ) 13 | 3 | 1
12 | 3 | 1
11 | 3 | 1

2

2

2

a | z | z
a | y | y
a | x | x
= | -
= | -
= | - | ( | )
( | )
( | ) 23 | 3 | 2
22 | 3 | 2
21 | 3 | 2

2

2

2

a | z | z
a | y | y
a | x | x
= | -
= | -
= | -

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
1 | 1
b | r | r | x | y | z | x | y | z
b | r | r | x | y | z | x | y | z
= | - - | - | - | + | + | +
= | - - | - | - | + | + | +

Solve for z in (A.2) and (A.3):

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
1 = | - | - | (A.4)

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
2 = | - | - | (A.5)

Subtract (A.4) from (A.5) to eliminate z and obtain x = f (y):

( ) 4 | 5 x = f y = a y + a | (A.6)

where:

1

2
4
a

a
a = - | 1
| 3
5
| a

a
a = - | 23

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
a = | - | 23
| | 22

13

12
2
a

a
a

a
a = | - | 13
| | 1

23

2
3
| | a b
a

b
a = -

Substitute (A.6) into (A.5) to eliminate x and obtain z = f (y):

( ) 6 | 7 z = f y = a y + a | (A.7)

where:

23

21 4 22
6
a
a a | a
a | - | - =

23

2 21 5
7
a
b | a a
a | - =

Now substitute (A.6) and (A.7) into the first equation in (A.1) to eliminate x and z and obtain a single quadratic in y only:

0 ²
ay +by + c = | (A.8)
where:
( | ) | ( | )
( | )( | ) | 2
| | | 1

2
1

2
1

2
5 5 | 1 | 7 7 | 1 | 1
4 5 | 1 | 1 | 6 7 | 1
| 2
6

2
4
2 | 2
2 | 2 | 2

1

c a a | x | a a | z | x | y | z | r
b | a a | x | y | a a | z
a a | a
= | - | + | - | + + | + -
= | - | - | + | -
= | + +

There are two solutions for y:

a

b | b | ac
y | 2
4 ² - ± | - ± = | (A.9)

To complete the intersection of three spheres solution, substitute both y values y+ and y- from (A.9) into (A.6) and (A.7):

4 | 5 x = a y +a ± | ± | (A.10)
6 | 7 z = a y +a ± | ± | (A.11)

In general there are two solutions, one corresponding to the positive and the second to the negative in (A.9). Obviously, the + and – solutions cannot be switched:
{ | }T
x | y | z + | + | + | { | }T
x | y | z - | - | - | (A.12)

Example
Let us now present an example to demonstrate the solutions in the intersection of three spheres algorithm. Given three spheres (c,r):
( | ) { | } 0 0 0 , 2 | 3 0 0 , 5 | 1 | 3 1 ,3 ({ | } | ) ({ | } ) T | T | T
- (A.13)

The intersection of three spheres algorithm yields the following two valid solutions:
{ | }{ | } T | T
x+ y+ z+ | = 1 0 1 | { | } { | } T | T
x- y- z- | = 1 -0.6 -0.8 | (A.14)

These two solutions may be verified by a 3D sketch. This completes the intersection of three spheres algorithm. In the next subsections we present several important topics related to this three-spheres intersection algorithm: imaginary solutions, singularities, and multiple solutions.

Imaginary Solutions
The three spheres intersection algorithm can yield imaginary solutions. This occurs when the
radicand b | 4ac
2 - | in (A.9) is less than zero; this yields imaginary solutions for ±y , which physically
means not all three spheres intersect. If this occurs in the hardware, there is either a joint angle sensing error or a modeling error, since the hardware should assemble properly.
A special case occurs when the radicand b | 4ac
2 - | in (A.9) is equal to zero. In this case, both
solutions have degenerated to a single solution, i.e. two spheres meet tangentially in a single point, and the third sphere also passes through this point.

Singularities
The three spheres intersection algorithm and hence the overall forward pose kinematics solution is subject to singularities. These are all algorithmic singularities, i.e. there is division by zero in the mathematics, but no problem exists in the hardware (no loss or gain in degrees of freedom). This subsection derives and analyzes the algorithmic singularities for the three spheres intersection algorithm presented above. Different possible three spheres intersection algorithms exist, by combining different equations starting with (A.1) and eliminating and solving for different variables first. Each has a different set of algorithmic singularities. We only analyze the algorithm presented above.
Inspecting the algorithm, represented in equations (A.1) – (A.12), we see there are four singularity conditions, all involving division by zero.

Singularity Conditions

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
(A.15)

The first two singularity conditions:

a | zz 13 | 3 | 1 = 2 | 0 ( - | =) | (A.16)
a | zz 23 | 3 | 2 = 2 | 0 ( - | =) | (A.17)

are satisfied when the centers of spheres 1 and 3 or spheres 2 and 3 have the same z coordinate, i.e.
1 | 3 z = z or 2 | 3 z = z . Therefore, in the nominal case where all four virtual sphere centers have the same z
height, this three-spheres intersection algorithm is always singular. An alternate solution is presented in Appendix B to overcome this problem.

The third singularity condition,

0
23

21

13

11
1 = | - | = a

a
a

a
a | | | | | | (A.18)

Simplifies to:

3 | 2
3 | 2
3 | 1
3 | 1
z | z
x | x
z | z
x | x
- = -
- (A.19)

For this condition to be satisfied, the centers of spheres 1, 2, and 3 must be collinear in the XZ plane. In general, singularity condition 3 lies along the edge of the useful workspace and thus presents no problem in hardware implementation if the system is properly designed regarding workspace limitations.

The fourth singularity condition,
1 0 ²
6

2
a = a4 + + a = | (A.20)

Is satisfied when:
1 ²
6

2
a4 +a = - | (A.21)

It is impossible to satisfy this condition as long as a4 and a6 from (A.6) and (A.7) are real numbers, as is the case in hardware implementations. Thus, the fourth singularity condition is never a problem.

Multiple Solutions

In general the three spheres intersection algorithm yields two distinct, correct solutions ( ± in (A.9 – A.11)). Generally only one of these is the correct valid solution, determined by the admissible Delta Robot assembly configurations.

Appendix B. Simplified Three-Spheres Intersection Algorithm

We now derive the equations and solution for the intersection point of three given spheres, assuming all three spheres have identical vertical center heights. Assume that the three given spheres
are ( 1c ,r1), ( 2 c ,r2), and ( 3 c ,r3). | That is, center vectors 1 | 1 | 1 | 1 { | }T
c = x yz | , 2 | 2 | 2 | 2 { | }T
c = x | y | z | ,
3 | 3 | 3 | 3 { | }T
c = x | y | z | , and radii r1, r2, and r3 are known. The three sphere center vectors must be expressed
in the same frame, {B} here, and the answer will be in the same coordinate frame. The equations of the three spheres to intersect are (choosing the first three spheres):
2 | 2 | 2 | 2
1 | 1 | 1 ( | ) | ( | ) | ( | ) n x - x | yy | zz | r +- | +- | = | (B.1)
2 | 2 | 2 | 2
2 | 2 | 2 ( | ) | ( | ) | ( | ) n x - x | yy | zz | r +- | +- | = | (B.2)
2 | 2 | 2 | 2
3 | 3 | 3 ( | ) | ( | ) | ( | ) n x - x | yy | zz | r +- | +- | = | (B.3)
Since all Z sphere-center heights are the same, we have 1 | 2 | 3 | n zz | z | z = == . The unknown three-
spheres intersection point is | { | }T P = x yz . Expanding (1-3) yields:
2 | 2 | 2 | 2 | 2 | 2 | 2
1 | 1 | 1 | 1 | 1 2 | 2 | 2 n | n x - xx x | y | yy y | z | z z z | r ++- | ++- | += | (B.4)
2 | 2 | 2 | 2 | 2 | 2 | 2
2 | 2 | 2 | 2 | 2 2 | 2 | 2 n | n x - xx x | y | yy y | z | zz z | r ++- | ++- | += | (B.5)
2 | 2 | 2 | 2 | 2 | 2 | 2
3 | 3 | 3 | 3 | 3 2 | 2 | 2 n | n x - xx x | y | yy y | z | zz z | r ++- | ++- | += | (B.6)

Subtracting (6) from (4) and (6) from (5) yields:

2 | 2 | 2 | 2 | 2 | 2
3 | 1 | 3 | 1 | 1 | 1 | 3 | 3 | 1 | 3 2( | ) | 2( | ) x - xx | y | yy x | y | x | y | r | r + | - | ++-- =- | (B.7)
2 | 2 | 2 | 2 | 2 | 2
3 | 2 | 3 | 2 | 2 | 2 | 3 | 3 | 2 | 3 2( | ) | 2( | ) x - xx | y | yyx | y | x | y | r | r + | - | ++-- =- | (B.8)

All non-linear terms of the unknowns x, y cancelled out in the subtractions above. Also, all z-related terms cancelled out in the above subtractions since all sphere-center z heights are identical. Equations (7-8) are two linear equations in the two unknowns x, y, of the following form.

ab x | c
de y | f
é | ùì ü ì ü ê | ú í ý íý =
ë | ûî þ î þ

(B.9)

where:

3 | 1
3 | 1
2 | 2 | 2 | 2 | 2 | 2
1 | 3 | 1 | 1 | 3 | 3
3 | 2
3 | 2
2 | 2 | 2 | 2 | 2 | 2
2 | 3 | 2 | 2 | 3 | 3
2( | )
2( | )
2( | )
2( | )
a | x | x
b | y | y
cr | r | x | y | x | y
d | x | x
e | y | y
f r | r | x | y | x | y
= | -
= | -
=--- ++
= | -
= | -
=--- ++

The unique solution for two of the unknowns x, y is:

ce bf x ae bd

af cd y ae bd

- = | -
- = | -

(B.10)

Returning to (1) to solve for the remaining unknown z:

2 Az | Bz C + | += 0 | (B.11)

where:

2 | 2 | 2 | 2
1 | 1 | 1

1
2
( | ) | ( | )

n

n

A
B | z
C z | r | xx | yy

=
=-
= -+- +-

Knowing the unique values x, y, the two possible solutions for the unknown z are found from the quadratic formula:

2

,

4
2 pm
B | B | C
z
-± | - = | (B.12)

For the Delta Robot, ALWAYS choose the z height solution that is below the base triangle, i.e. negative z, since that is the only physically-admissible solution.

This simplified three-spheres intersection algorithm solution for x, y, z fails in two cases:

i) When the determinant of the coefficient matrix in the x, y, linear solution (B.10) is zero.
3 | 1 | 3 | 2 | 3 | 1 | 3 | 2 ae bd | x x | y y | y y x x -= | - | - - | - | - = 2( | )2( | ) 2( | )2( | ) 0 | (B.13)

This is an algorithmic singularity whose condition can be simplified as follows. (B.13) becomes:

3 | 1 | 3 | 2 | 3 | 1 | 3 | 2 ( | )( | ) ( | )( | ) x - xy | y | y | yx | x - | = | - | - | (B.14)

If (B.14) is satisfied there will be an algorithmic singularity. Note that the algorithmic singularity condition (B.14) is only a function of constant terms. Therefore, this singularity can be avoided by design, i.e. proper placement of the robot base locations in the XY plane. For a symmetric Delta Robot, this particular algorithmic singularity is avoided by design.

ii) | When the radicand in (B.12) is negative, the solution for z will be imaginary. The condition
2 B | C - | < 4 | 0 yields:
2 | 2 | 2
1 | 1 | 1 ( | ) | ( | ) x - x | yy | r +- | > | (B.15)

When this inequality is satisfied, the solution for z will be imaginary, which means that the robot will not assemble for that configuration. Note that (B.15) is an inequality for a circle. This singularity will NEVER occur if valid inputs are given for the FPK problem, i.e. the Delta Robot assembles.

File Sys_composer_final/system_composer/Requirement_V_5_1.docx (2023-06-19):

F11.14 When <input ‘Logout Prompt’ is received >the function <F11.14> shall generate <output ‘Logout Confirm’ and ‘DB Updated’ >.

F11.15 When <input ‘Show Parameters’ is received >the function <F11.15> shall generate <output ‘system state’ and ‘Logout Prompt’ and ‘Observe Parameters’>.

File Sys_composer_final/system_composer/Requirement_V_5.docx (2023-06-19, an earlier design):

F1 Detect

F1.1 When <input ‘System Ready’ is received >the function <F1.1> shall generate <output ‘SystemCalibrated’ >.

F1.2 When <input ‘SystemCalibrated’ is received, input ‘LookForProduct’ is received

AND input ‘Reset Signal’ is received the function <F1.2> shall generate <output ‘InterpretSignal’ >.

F1.3 When <input ‘InterpretSignal’ is received AND input ‘Product’ is received>the function <F1.3> shall generate <output ‘Product Detected’ AND ’Count’>.

F2 Inspect

F2.1 When <input: ‘Product’>, The function<F2.1>Shall generate <output: ‘OutBus’>

F2.2 When <input: ‘Detection signal’>, The function<F2.2>Shall generate <output: ‘Trigger’>

F2.3 When <input: ‘Product AND Power AND Trigger’>, The function<F2.3>Shall generate <output: ‘Product Image AND OutBus AND OutBus1’>

F2.4 When <input: ‘Product Image’>, The function<F2.4>Shall generate <output: ‘ProductOrientation’>

F2.5 When <input: ‘Product Image’>, The function<F2.5>Shall generate <output: ‘ExtractedQRCode’>

F2.6 When <input: ‘ExtractedQRCode’>, The function<F2.6>Shall generate <output: ‘ExportQR’>

F2.7 When <input: ‘Product Image’>, The function<F2.7>Shall generate <output: ‘Dimension of product’>

F2.7.1 When <input: ‘Product Image’>, The function<F2.7.1>Shall generate <output: ‘Coordinates’>

F2.7.2 When <input: ‘Coordinates’>, The function<F2.7.2>Shall generate <output: ‘Dimension of product’>

F2.8 When <input: ‘Product Image’>, The function<F2.7>Shall generate <output: ‘ProductPosition’>

F3 Compare Dimensions

F3.1 When <input ‘Dimension of product’ is received >the function <F3.1> shall generate <output ‘ImportedDimensions’ >.

F3.2 When <input ‘ImportedDimensions’ is received >the function <F3.2> shall generate <output ‘ReferDBDimensions’ AND ‘CurrentDimensions’>.

F3.3 When <input ‘ReferDBDimensions’ is received >the function <F3.3> shall generate <output ‘DBDimensions’ >.

F3.4 When <input ‘DBDimensions’ is received >the function <F3.4> shall generate <output ‘ExpectedDimensions’ >.

F3.5 When <input ‘ExpectedDimensions’ is received AND input ‘CurrentDimensions’ is received >the function <F3.5> shall generate <output ‘Faulty Product Detected’ AND ‘BeginPickOperation’>.

F4 Calibrate

F4.1 When <input: ‘Power AND Motor AND Frame components’>, The function<F4.1>Shall generate <output: ‘ConfirmSetup’>.

F4.1.1 When <input: ‘Frame components’>, The function<F4.1.1>Shall generate <output: ‘Frame’>.

F4.1.2 When <input: ‘Motor AND Frame’>, The function<F4.1.2>Shall generate <output: ‘Frame and motor setup’>.

F4.1.3 When <input: ‘Frame and motor setup AND Power’>, The function<F4.1.3>Shall generate <output: ‘Physical setup -> ConfirmSetup’>.

F4.2 When <input: ‘UIReady’>, The function<F4.2>Shall generate <output: ‘Trigger’>.

F4.3 When <input: ‘Trigger AND SetupConfirmation AND Power’>, The function<F4.3>Shall generate <output: ‘JogComplete’>.

F4.4 When <input: ‘JogComplete AND Power’>, The function<F4.4>Shall generate <output: ‘Robot at home position -> ConfirmCalibration’>.

F5 Pick Product

F Begin Task When <input: ‘Beiginpickoperation’>, The function<F Begin Task>Shall generate <output: ‘Coordintes AND Orientation’>.

F5.1 When <input: ‘Coordinates’>, The function<F5.1>Shall generate <output: ‘Importedcoordiantes’>.

F5.2 When <input: ‘Orientation’>, The function<F5.2>Shall generate <output: ‘Importedorientation’>.

F5.3 When <input: ‘Importedorientation AND Importedcoordinates AND New coordinates ’>, The function<F5.3>Shall generate <output: ‘Current Position AND Defined Path’>.

F5.4 When <input: ‘Corrected Postition AND Corrected Force’>, The function<F5.4>Shall generate <output: ‘New coordinates AND New Force value’>.

F5.5 When <input: ‘Defined Path’>, The function<F5.5>Shall generate <output: ‘Ready to pick Pick Product’>.

F5.6 When <input: ‘New Force value AND Ready to pick Pick Product ’>, The function<F5.6>Shall generate <output: ‘Product Picked AND Current Force’>

F6 Translate Product

F6.1 When <input ‘Product Picked’ is received >the function <F6.1> shall generate <output ‘Ready to be Placed’ >.

F7 Place Product

F7.1 When <input ‘Corrected Position’ is received >the function <F7.1> shall generate <output ‘New Position’ >.

F7.2 When <input ‘Ready to be placed’ is received AND input ‘New Position’ is received>the function <F1.3> shall generate <output ‘Gripper Lowered’ >.

F7.3 When <input ‘Gripper Lowered’ is received >the function <F7.3> shall generate <output ‘Product Released’ >.

F7.4 When <input ‘Product Released’ is received >the function <F7.4> shall generate <output ‘Product Placed’ >.

F08 Handle Contingencies

F8.1 When <input ‘Force on gripper’ is received >the function <F8.1> shall generate <output ‘Appropriate force’ >.

F9 Hold Operations

F9.1 When <input ‘Product Not Detected’ is received >the function <F9.1> shall generate <output ‘Return To Detection’ >.

F10 Halt Operations

F10.1 When <input ‘EmergencyStopSignal’ is received >the function <F10.1> shall generate <output ‘RecievedInput’ >.

F10.2 When <input ‘RecievedInput’ is received >the function <F10.2> shall generate <output ‘StopOperation’ >.

F10.3 When <input ‘StopOperation’ is received >the function <F10.3> shall generate <output ‘Stop Signal’ AND ‘NotifyOperator’>.

F10.3 When <input ‘NotifyOperator’ is received >the function <F10.4> shall generate <output ‘NotifySTOP’ >.

F11.Handle User Interface

F1.1 When <input ‘Reset Confirmation’ is received >the function <F1.1> shall generate <output ‘Logout Successful’ >.

F11.2 When <input ‘Power Supply’ is received >the function <F11.2> shall generate <output ‘WaitforInput’ >.

F13.3 When <input ‘Receive User Input’ is received >the function <F11.3> shall generate <output ‘Ready to Interact’ >.

F11.4 When <input ‘Provide User Interface’ is received >the function <F11.4> shall generate <output ‘VisualsReady’ >.

F11.5 When <input ‘VisualsReady’ and ‘User Credentials’ is received >the function <F11.5> shall generate <output ‘Received Credentials’ >.

F11.6 When <input ‘Received Credentials’ is received >the function <F11.6> shall generate <output ‘Confirmation’ >.

F11.7 When <input ‘Confirmation’ is received >the function <F11.7> shall generate <output ‘Login Confirm’ and ‘Open Dashboard’ >.

F11.8 When <input ‘Open Dashboard’ is received >the function <F11.8> shall generate <output ‘Dashboard Loaded’ >.

F11.9 When <input ‘Stop Button’ is received >the function <F11.9> shall generate <output ‘Notify Emergency’ >.

F11.10 When <input ‘Dashboard Loaded’ and ‘Faulty Product Detected’ and ‘Count’ and ‘Observe parameter’ is received > the function <F11.10> shall generate <output ‘Notify Emergency’ >.

F11.11 When <input ‘Notify Emergency’ is received >the function <F11.11> shall generate <output ‘’ >.

F11.12 When <input ‘Logout Confirmed’ and ‘Stop Confirm’ is received >the function <F11.12> shall generate <output ‘Reset system’ >.

F11.13 When <input ‘DB Updated’ is received >the function <F11.13> shall generate <output ‘Stop Operation’ >.

F12 Reset Position

F12.1 When <input ‘Product placed’ is received OR ‘Log-out’ is received >the function <F12.1> shall generate <output ‘home position’ >.

F12.2 When <input ‘home position’ is received >the function <F12.2> shall generate <output ‘power off signal’ AND ‘Coordinates’ >.

F12.3 When <input ‘power off signal’ is received >the function <F12.3> shall generate <output ‘System ready’ >.

F12.4 When <input ‘Coordinates’ is received >the function <F12.4> shall generate <output ‘HoldAtHomePosition’ >.

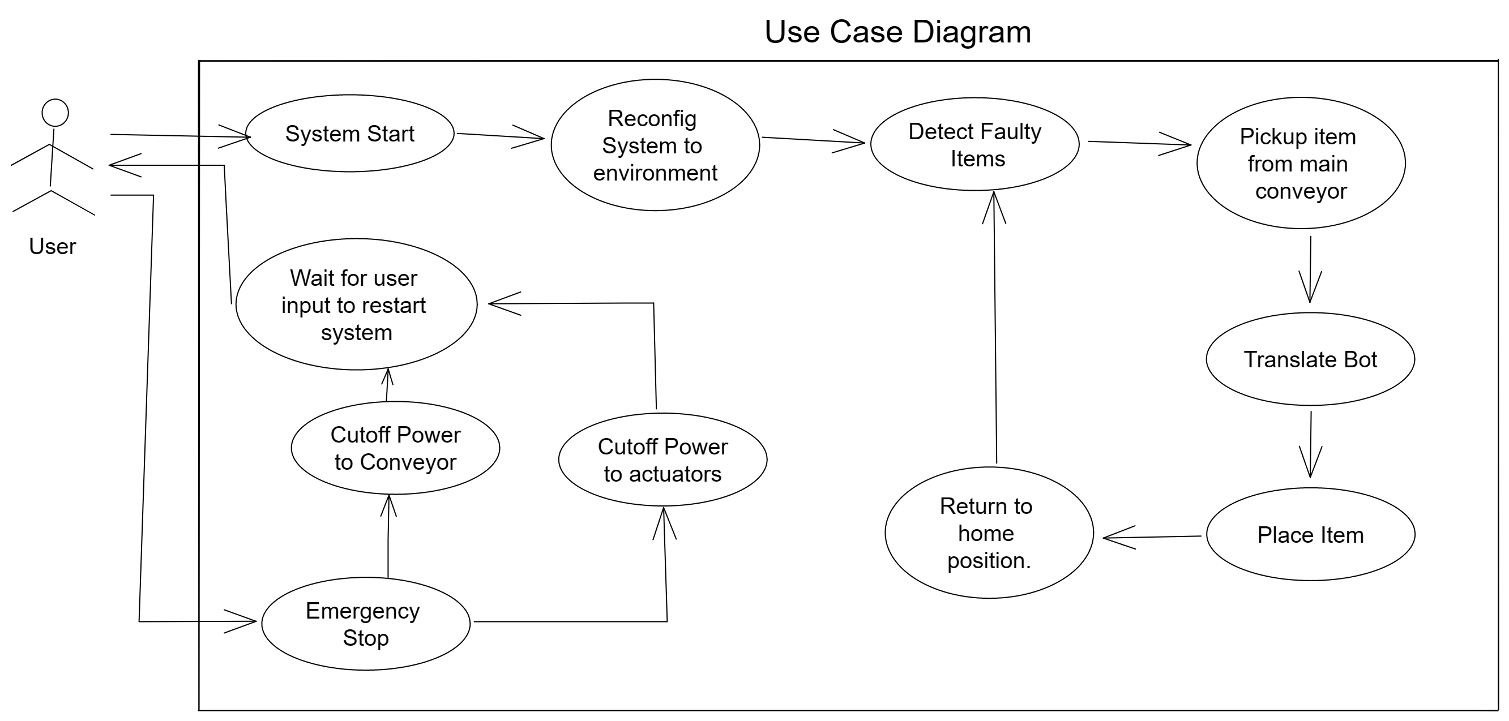
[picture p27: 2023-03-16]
UML/Untitled-2023-03-09-1120.png

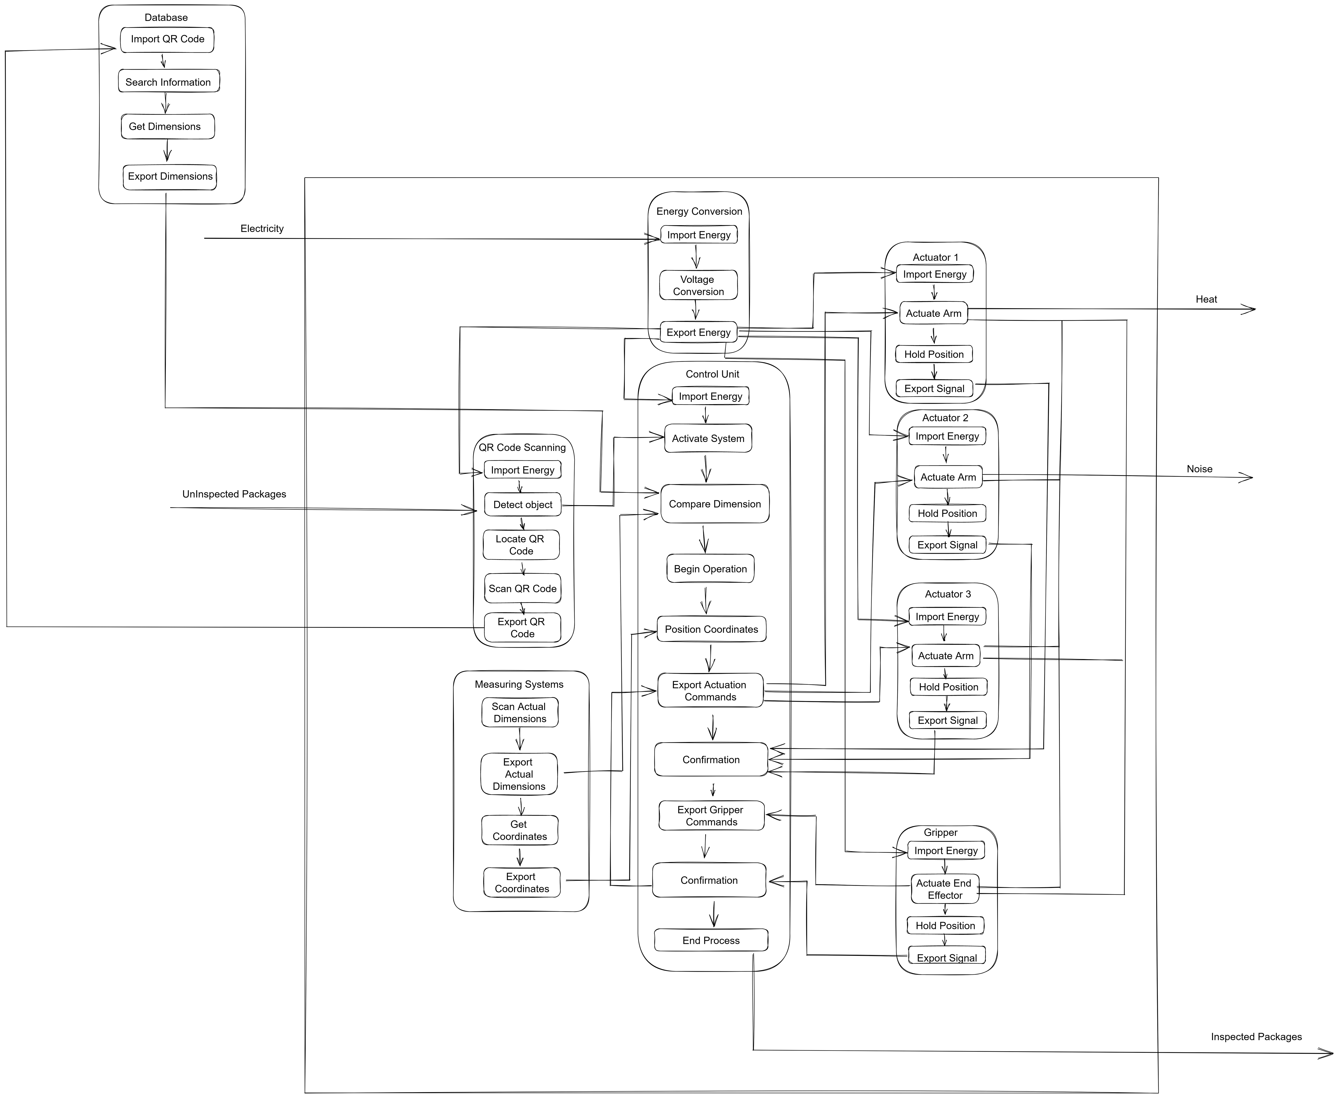
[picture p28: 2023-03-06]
FBD/Untitled-2023-03-06-1407.png

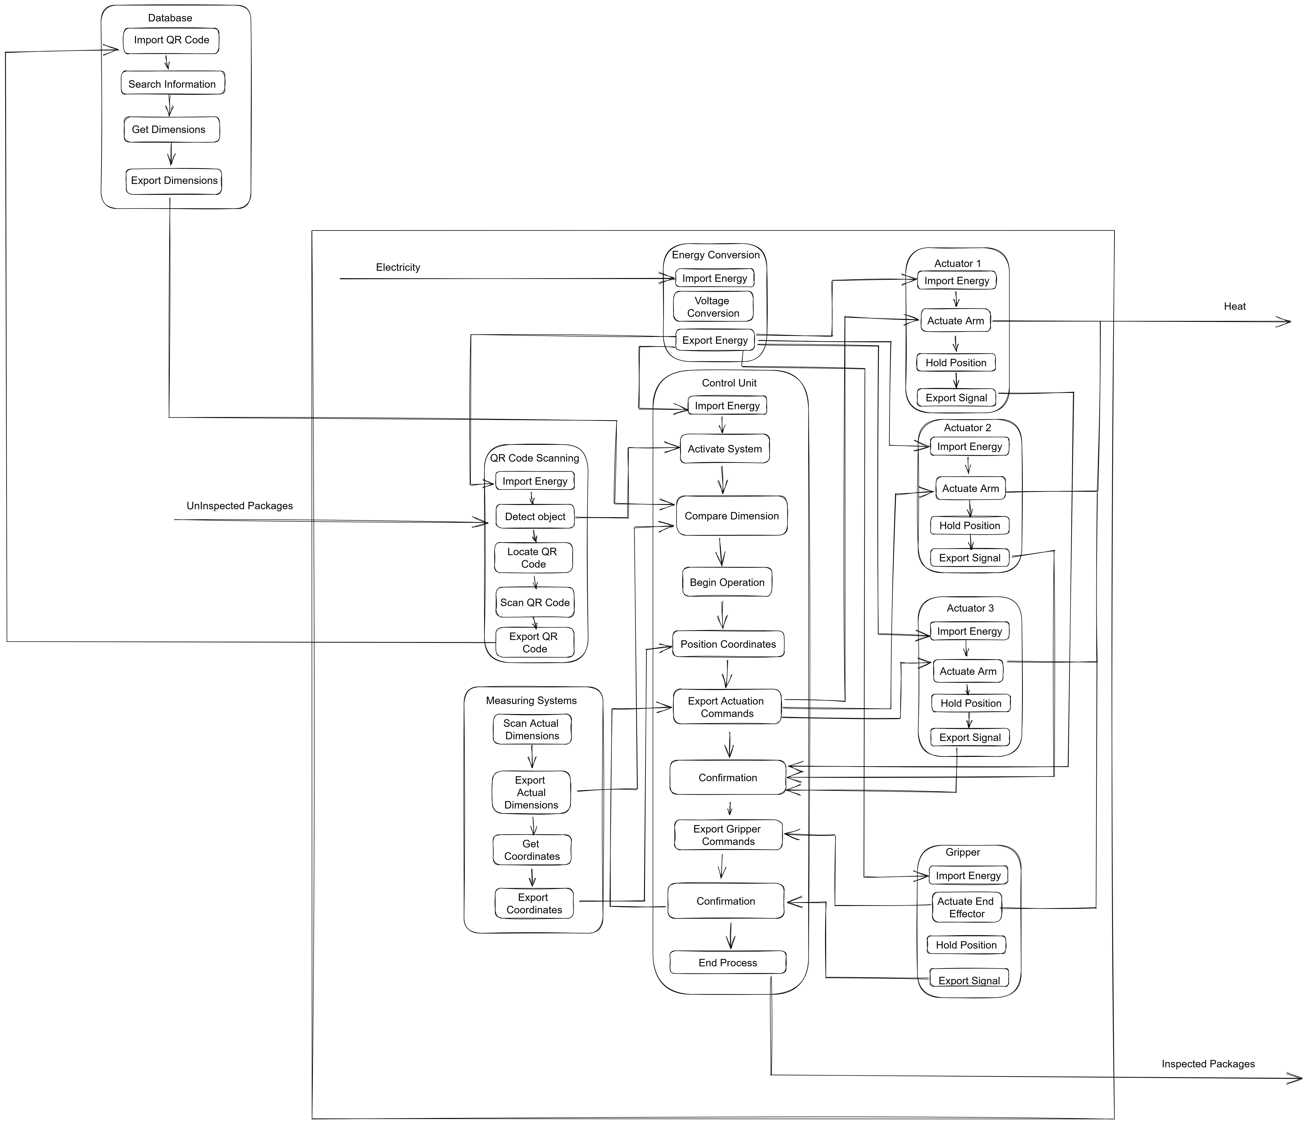
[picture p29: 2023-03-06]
FBD/Untitled-2023-02-22-1407.png

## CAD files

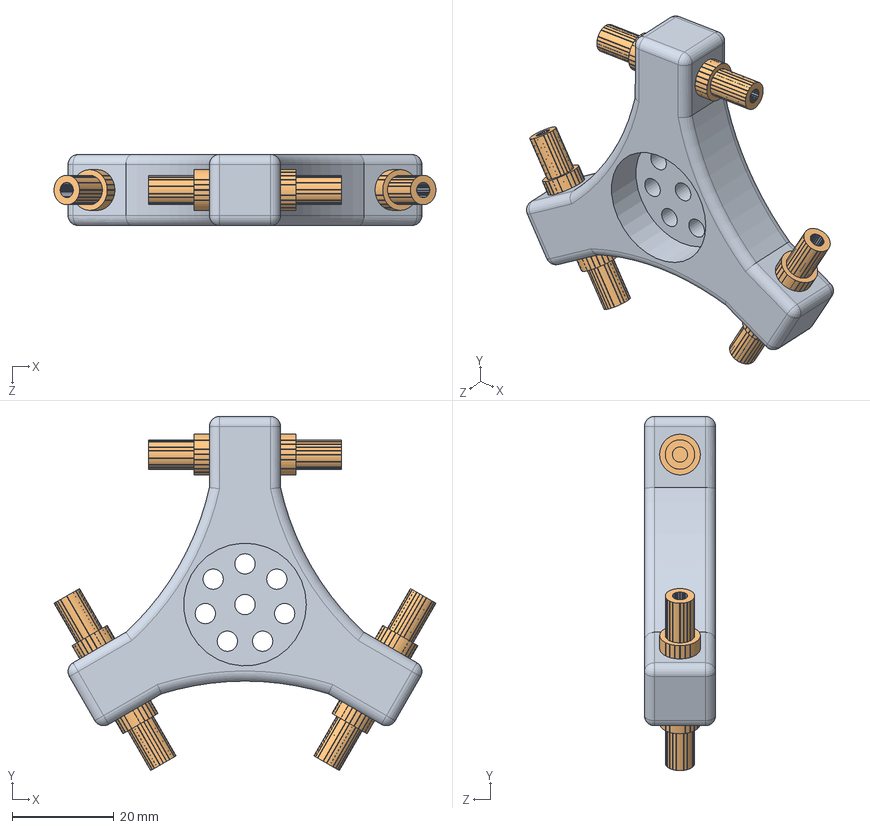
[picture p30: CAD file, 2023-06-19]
3d_design/liquid.SLDASM
75.1 x 69.7 x 14.0 mm
New_end_effector_holder - Copy

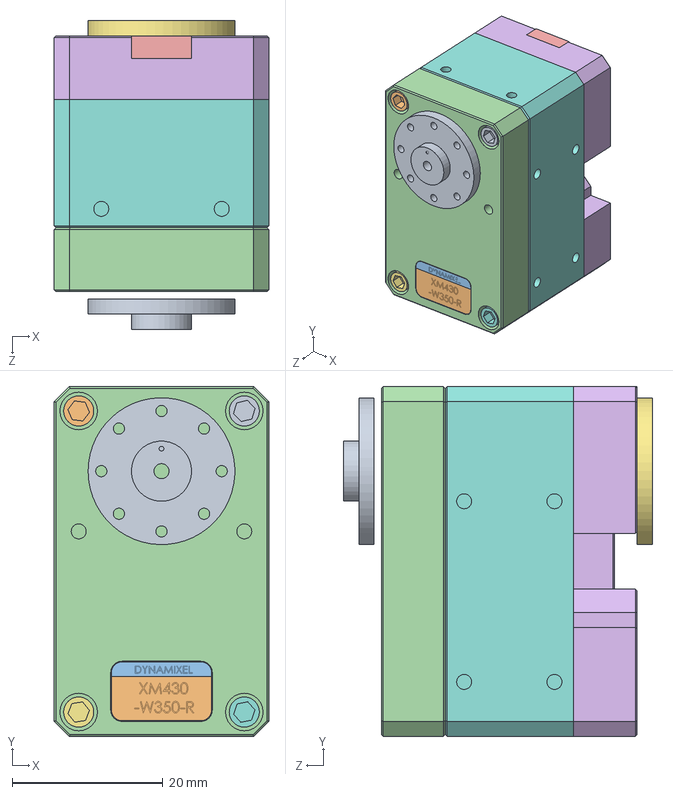
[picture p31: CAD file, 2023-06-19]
3d_design/XM430-W350-R.SLDASM
28.5 x 46.5 x 41.0 mm
Part 1.step
Part 2.step
Part 3.step
Part 4.step
Part 5.step
Part 6.step
Part 7.step
Part 8.step
Part 9.step
Part 10.step
Part 11.step
Part 12.step
Part 13.step
Part 14.step
Part 15.step
Part 16.step

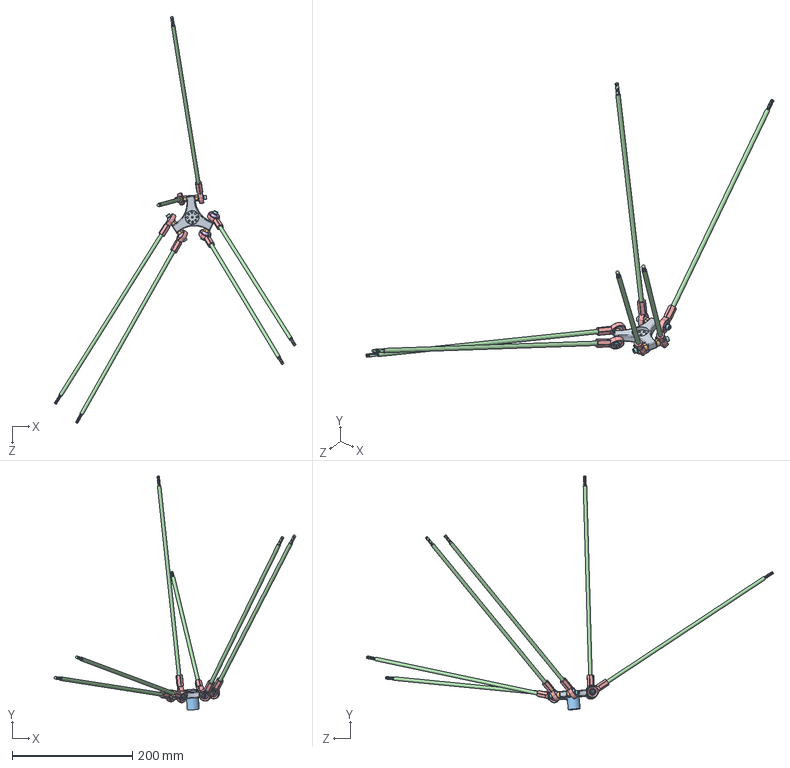
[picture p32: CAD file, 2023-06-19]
3d_design/LOWER_LINK_SUBASSEMBLY.SLDASM
402.5 x 389.5 x 677.7 mm
end_effector
END_EFFECTOR_PIN x 6
magnetic_gripper
lower_link x 6
KCRM-06-01 x 6
KCRM-06 -02 x 6
spring lock washer 6735_is x 6
socket head cap screw_is x 6

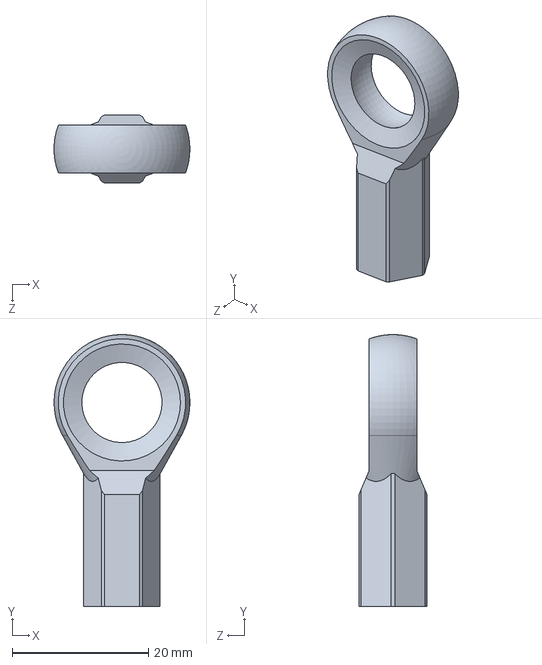
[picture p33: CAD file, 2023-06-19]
3d_design/KCRM-06 (0).SLDASM
20.0 x 40.0 x 10.0 mm

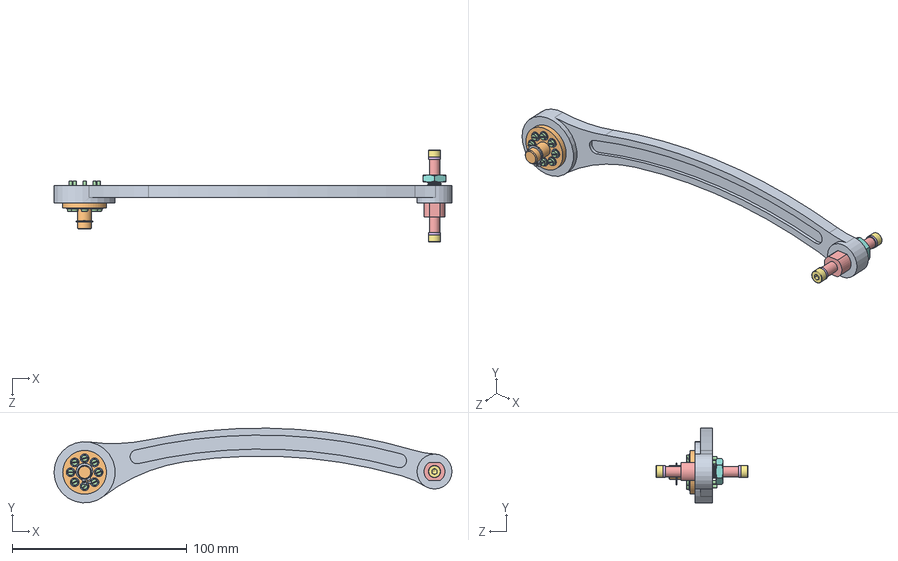
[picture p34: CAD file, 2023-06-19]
3d_design/LINK1_SUBASSEMBLY.SLDASM
227.5 x 42.7 x 52.4 mm
link1
horn
plain washer (type a)_is x 8
slotted cheese head_is x 8
custom_pin
spring lock washer 6735_is x 2
socket head cap screw_is x 2
hexagon thin nut (ch)_is
(normal) external_is

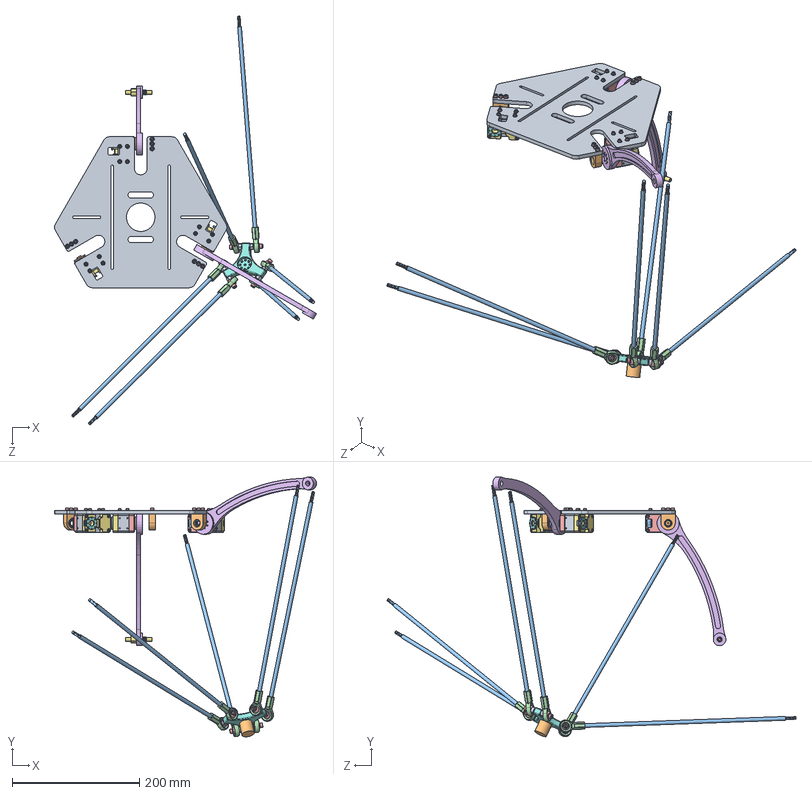
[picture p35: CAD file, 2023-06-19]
3d_design/FRAME_SUBASSEMBLY.SLDASM
412.4 x 408.7 x 643.4 mm
base_XM430
Part 1.step x 3
Part 2.step x 3
Part 3.step x 3
Part 4.step x 3
Part 5.step x 3
Part 6.step x 3
Part 7.step x 3
Part 8.step x 3
Part 9.step x 3
Part 10.step x 3
Part 11.step x 3
Part 12.step x 3
Part 13.step x 3
Part 14.step x 3
Part 15.step x 3
Part 16.step x 3
bearing_block _xm x 3
single row radial ball bearing_is x 3
plain washer (type a)_is x 21
socket head cap screw_is x 27
link1 x 2
custom_pin
end_effector
END_EFFECTOR_PIN x 6
magnetic_gripper
lower_link x 6
KCRM-06-01 x 6
KCRM-06 -02 x 6
spring lock washer 6735_is x 6

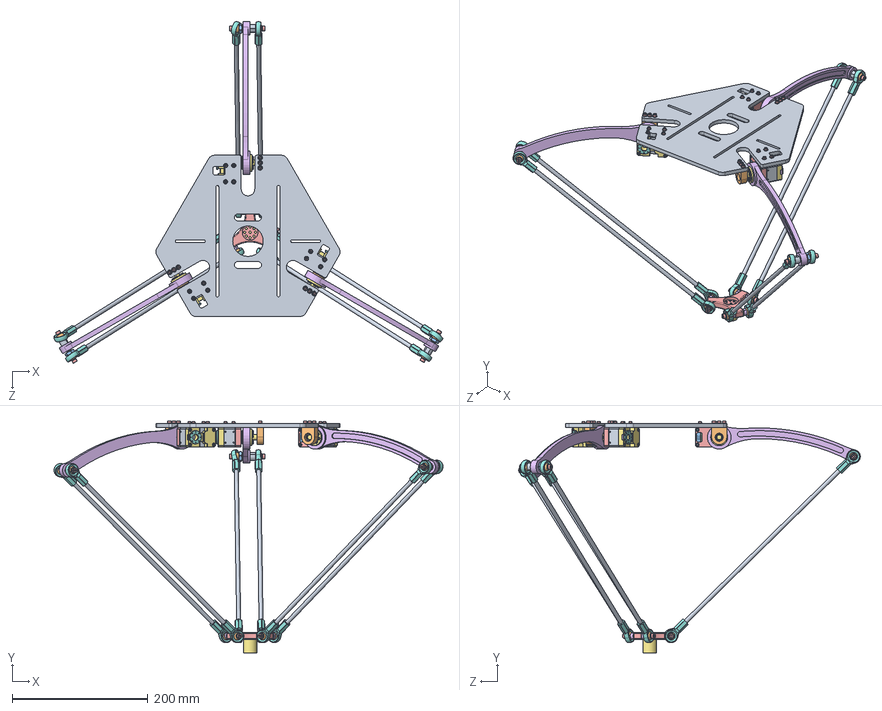
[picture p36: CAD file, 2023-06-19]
3d_design/DELTA_ROBOT.SLDASM
573.1 x 341.4 x 503.4 mm
base_XM430
Part 1.step x 3
Part 2.step x 3
Part 3.step x 3
Part 4.step x 3
Part 5.step x 3
Part 6.step x 3
Part 7.step x 3
Part 8.step x 3
Part 9.step x 3
Part 10.step x 3
Part 11.step x 3
Part 12.step x 3
Part 13.step x 3
Part 14.step x 3
Part 15.step x 3
Part 16.step x 3
bearing_block _xm x 3
single row radial ball bearing_is x 3
plain washer (type a)_is x 45
socket head cap screw_is x 33
link1 x 3
horn x 3
slotted cheese head_is x 24
custom_pin x 3
spring lock washer 6735_is x 12
hexagon thin nut (ch)_is x 3
(normal) external_is x 3
end_effector
END_EFFECTOR_PIN x 6
magnetic_gripper
KCRM-06-01 x 12
lower_link x 6
KCRM-06 -02 x 12

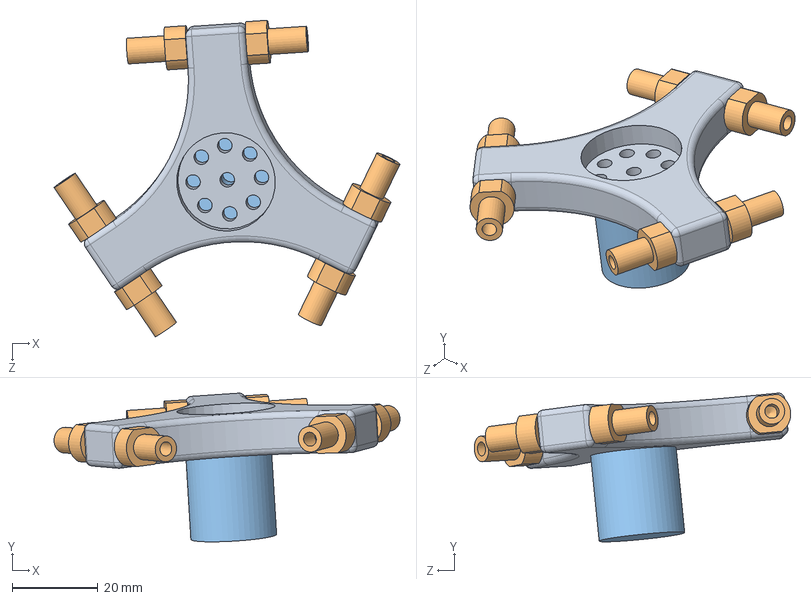
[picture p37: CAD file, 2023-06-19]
3d_design/end_effector_assembly.SLDASM
80.5 x 34.6 x 73.7 mm
end_effector
END_EFFECTOR_PIN x 6
magnetic_gripper

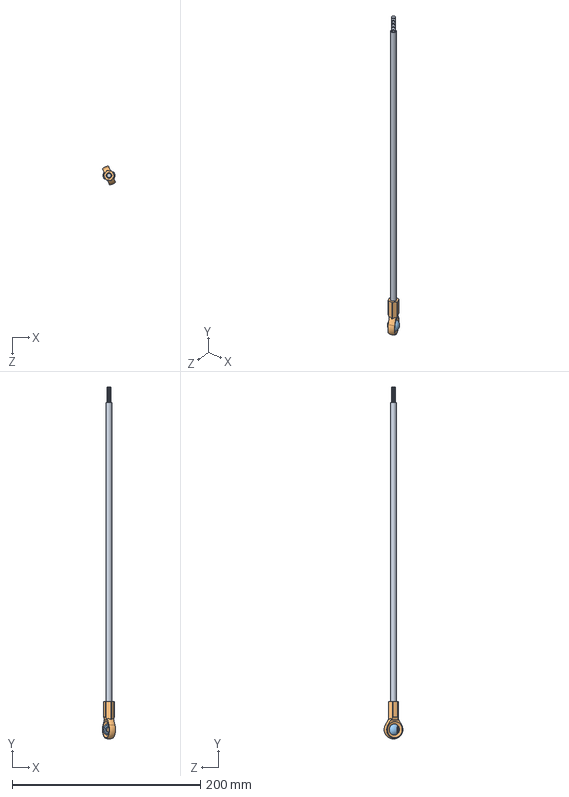
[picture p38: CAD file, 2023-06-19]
3d_design/lower_link_assembly.SLDASM
13.8 x 373.5 x 19.9 mm
lower_link
KCRM-06-01
KCRM-06 -02

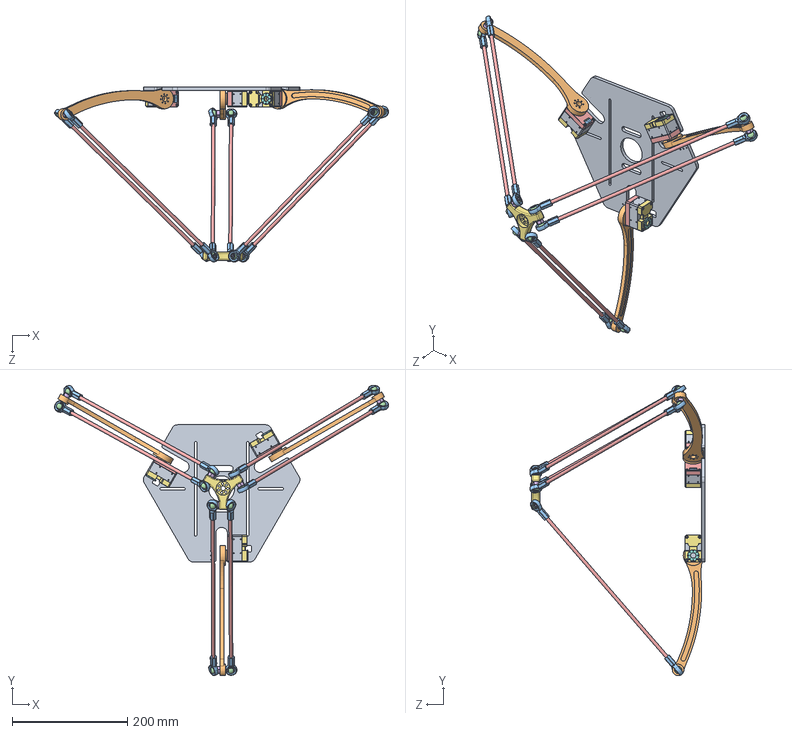
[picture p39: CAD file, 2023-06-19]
3d_design/Mat_1.SLDASM
578.6 x 503.0 x 303.1 mm
base_XM430
Part 1.step x 3
Part 2.step x 3
Part 3.step x 3
Part 4.step x 3
Part 5.step x 3
Part 6.step x 3
Part 7.step x 3
Part 8.step x 3
Part 9.step x 3
Part 10.step x 3
Part 11.step x 3
Part 12.step x 3
Part 13.step x 3
Part 14.step x 3
Part 15.step x 3
Part 16.step x 3
link1 x 3
KCRM-06-01 x 12
KCRM-06 -02 x 12
lower_link x 6
custom_pin x 6
New_end_effector_holder

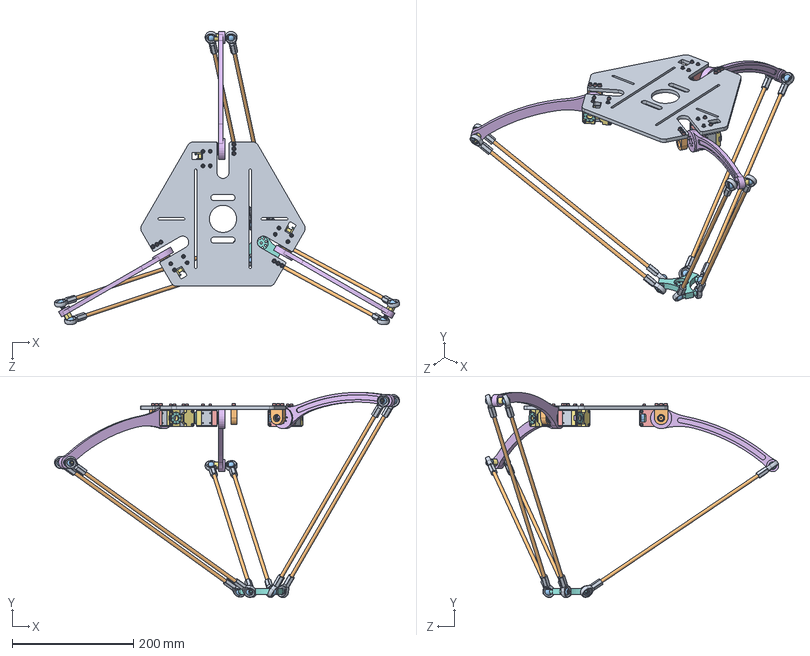
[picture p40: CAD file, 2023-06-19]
3d_design/Delta2.SLDASM
569.0 x 338.4 x 483.9 mm
base_XM430
Part 1.step x 3
Part 2.step x 3
Part 3.step x 3
Part 4.step x 3
Part 5.step x 3
Part 6.step x 3
Part 7.step x 3
Part 8.step x 3
Part 9.step x 3
Part 10.step x 3
Part 11.step x 3
Part 12.step x 3
Part 13.step x 3
Part 14.step x 3
Part 15.step x 3
Part 16.step x 3
bearing_block _xm x 3
single row radial ball bearing_is x 3
plain washer (type a)_is x 21
socket head cap screw_is x 21
link1 x 3
custom_pin x 3
end_effector_assembly
KCRM-06-01 x 12
lower_link x 6
KCRM-06 -02 x 12

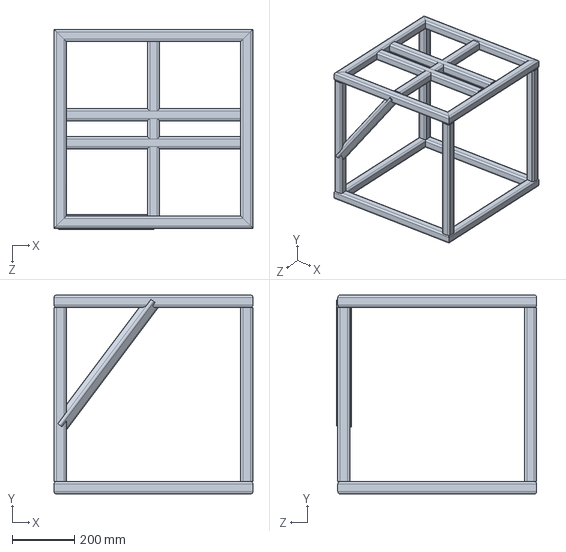
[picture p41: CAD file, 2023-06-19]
3d_design/ms_cube.SLDPRT
640.0 x 640.0 x 644.7 mm

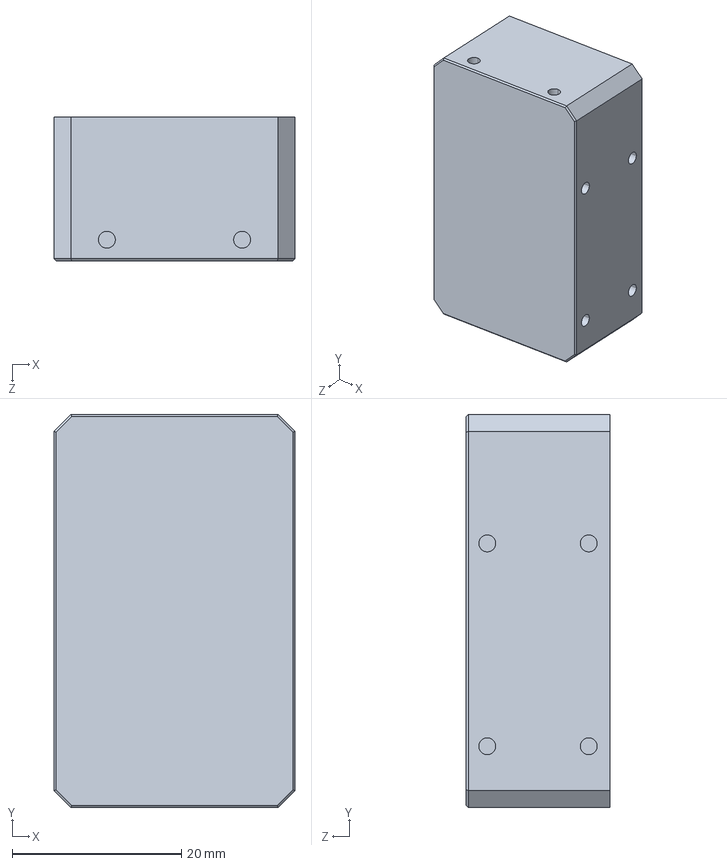
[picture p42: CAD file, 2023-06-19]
Delta_try_og/Part 16.step_Default_sldprt.STEP
28.5 x 46.5 x 17.0 mm

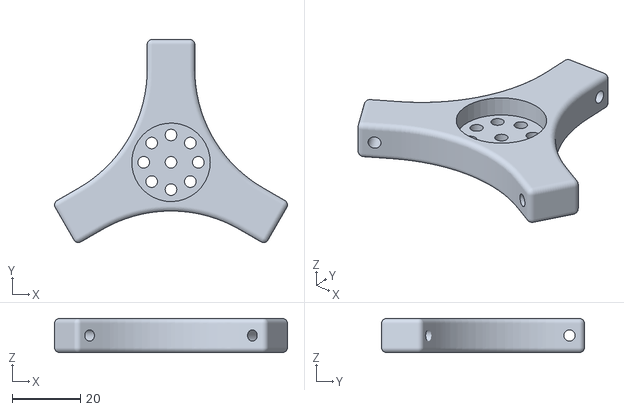
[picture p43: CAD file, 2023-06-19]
3d_design/ee.STL
68.3 x 59.5 x 10.0

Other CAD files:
3d_design/cube60x60.SLDASM
Delta_try_og/Part 1.step_Default_sldprt.STEP
3d_design/lower_link.SLDPRT
Delta_try_og/Part 2.step_Default_sldprt.STEP
3d_design/1.SLDPRT
3d_design/END_EFFECTOR_PIN.SLDPRT
3d_design/KCRM-06 -02.SLDPRT
3d_design/KCRM-06-01.SLDPRT
3d_design/New_end_effector_holder - Copy.SLDPRT
3d_design/New_end_effector_holder - Copy.STL
3d_design/New_end_effector_holder.SLDPRT
3d_design/New_pin.SLDPRT
3d_design/New_pin.STL
3d_design/base_XM430.DXF
3d_design/base_XM430.SLDDRW
3d_design/base_XM430.SLDPRT
3d_design/bearing_block _xm.SLDPRT
3d_design/cube.SLDPRT
3d_design/custom_pin _og.SLDPRT
3d_design/custom_pin.SLDDRW
3d_design/custom_pin.SLDPRT
3d_design/custom_pin.STL
3d_design/delta_base.DXF
3d_design/end_effector.SLDPRT
3d_design/end_effector_assembly.SLDPRT
3d_design/end_effector_assembly.STL
3d_design/horn.SLDPRT
3d_design/link1.SLDPRT
3d_design/liquid - 1-1.STL
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

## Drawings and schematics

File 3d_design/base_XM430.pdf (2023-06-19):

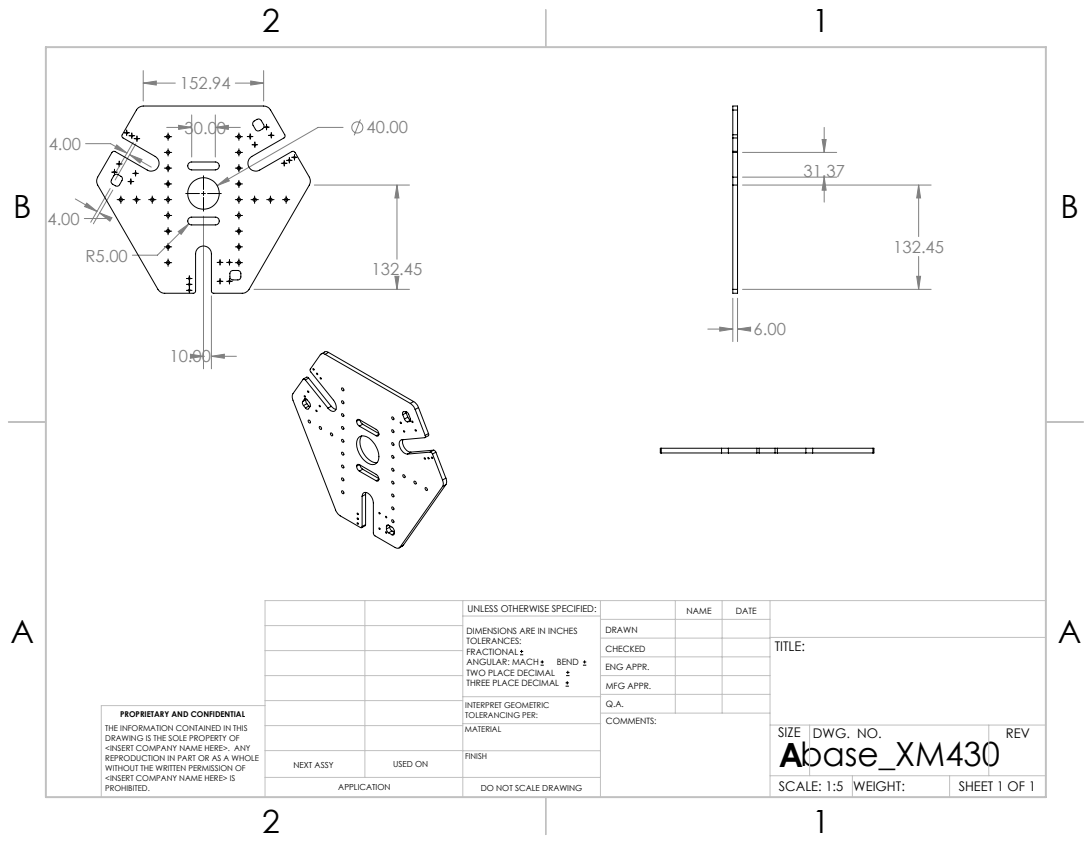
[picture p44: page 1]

UNLESS OTHERWISE SPECIFIED: | | NAME | DATE
DIMENSIONS ARE IN INCHES TOLERANCES: FRACTIONAL ANGULAR: MACH BEND TWO PLACE DECIMAL THREE PLACE DECIMAL | DRAWN

CHECKED | | | TITLE:

ENG APPR.
MFG APPR.

INTERPRET GEOMETRIC TOLERANCING PER: | Q.A.
MATERIAL | | SIZE A base_XM430 | DWG. NO. | REV

PROPRIETARY AND CONFIDENTIAL
THE INFORMATION CONTAINED IN THIS
DRAWING IS THE SOLE PROPERTY OF
<INSERT COMPANY NAME HERE>. ANY
REPRODUCTION IN PART OR AS A WHOLE
WITHOUT THE WRITTEN PERMISSION OF
<INSERT COMPANY NAME HERE> IS
PROHIBITED.

NEXT ASSY | USED ON | FINISH

APPLICATION | DO NOT SCALE DRAWING | | SCALE: 1:5 | WEIGHT: | SHEET 1 OF 1

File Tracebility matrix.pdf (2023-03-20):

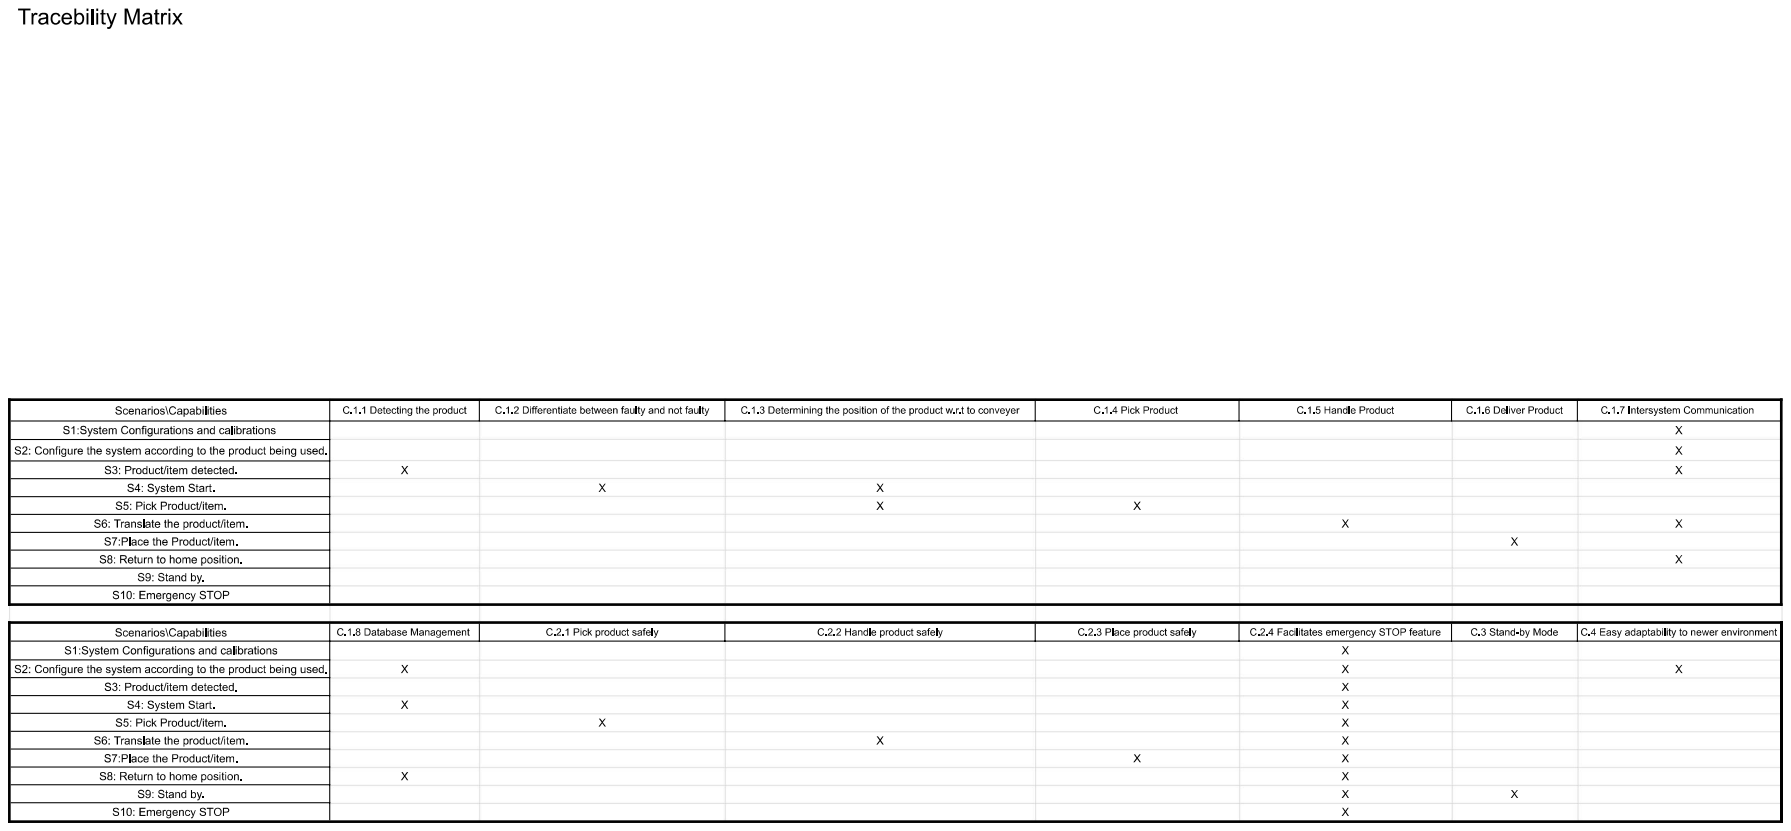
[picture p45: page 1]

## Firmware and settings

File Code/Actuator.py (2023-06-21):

import os


if os.name == 'nt':
    import msvcrt
    def getch():
        return msvcrt.getch().decode()
else:
    import sys, tty, termios
    fd = sys.stdin.fileno()
    old_settings = termios.tcgetattr(fd)
    def getch():
        try:
            tty.setraw(sys.stdin.fileno())
            ch = sys.stdin.read(1)
        finally:
            termios.tcsetattr(fd, termios.TCSADRAIN, old_settings)
        return ch

from dynamixel_sdk import * 

Current_Deg=[0,0.0,0.0,0.0]

class Actuate():
    ADDR_TORQUE_ENABLE          = 64
    ADDR_GOAL_POSITION          = 116
    ADDR_PRESENT_POSITION       = 132
    ADDR_PROFILE_VELOCITY       = 112
    DXL_MINIMUM_POSITION_VALUE  = 1000      # Refer to the Minimum Position Limit of product eManual
    DXL_MAXIMUM_POSITION_VALUE  = 2600      # Refer to the Maximum Position Limit of product eManual
    BAUDRATE                    = 57600

    PROTOCOL_VERSION            = 2.0

    # Factory default ID of all DYNAMIXEL is 1
    DXL_ID0                      = 0
    DXL_ID1                      = 1
    DXL_ID2                      = 2
    # Use the actual port assigned to the U2D2.
    # ex) Windows: "COM*", Linux: "/dev/ttyUSB*", Mac: "/dev/tty.usbserial-*"
    DEVICENAME                  = "COM9"

    TORQUE_ENABLE               = 1     # Value for enabling the torque
    TORQUE_DISABLE              = 0     # Value for disabling the torque
    DXL_MOVING_STATUS_THRESHOLD = 20    # Dynamixel moving status threshold
    PROFILE_VELOCITY 			= 100   # Dynamixel Velocity

    index = 0
    dxl_goal_position = [DXL_MINIMUM_POSITION_VALUE, DXL_MAXIMUM_POSITION_VALUE]         # Goal position
    portHandler = PortHandler(DEVICENAME)
    packetHandler = PacketHandler(PROTOCOL_VERSION)
    
    Motor_ID_Dict={1:DXL_ID0 ,2:DXL_ID1, 3:DXL_ID2}

    def __init__(self):
        print("Init works!!!")
        if Actuate.portHandler.openPort():
            print("Succeeded to open the port")
        else:
            print("Failed to open the port")
            print("Press any key to terminate...")
            getch()
            quit()
        if Actuate.portHandler.setBaudRate(Actuate.BAUDRATE):
            print("Succeeded to change the baudrate")
        else:
            print("Failed to change the baudrate")
            print("Press any key to terminate...")
            getch()
            quit()
        Actuate.Enable_all_Motors()

    def enable_torque(id):
        dxl_comm_result, dxl_error = Actuate.packetHandler.write1ByteTxRx(Actuate.portHandler, Actuate.Motor_ID_Dict[id], Actuate.ADDR_TORQUE_ENABLE, Actuate.TORQUE_ENABLE)
        if dxl_comm_result != COMM_SUCCESS:
            print("%s" % Actuate.packetHandler.getTxRxResult(dxl_comm_result))
        elif dxl_error != 0:
            print("%s" % Actuate.packetHandler.getRxPacketError(dxl_error))
        else:
            print("\nTorque has been enabled for Motor ID: ",id)

    def enable_velocity(id):
        dxl_comm_result, dxl_error = Actuate.packetHandler.write4ByteTxRx(Actuate.portHandler, Actuate.Motor_ID_Dict[id], Actuate.ADDR_PROFILE_VELOCITY, Actuate.PROFILE_VELOCITY)
        if dxl_comm_result != COMM_SUCCESS:
            print("%s" % Actuate.packetHandler.getTxRxResult(dxl_comm_result))
        elif dxl_error != 0:
            print("%s" % Actuate.packetHandler.getRxPacketError(dxl_error))
        else:
            print("\nVelocity has been enabled for Motor ID: ",id)

    def actuate_motors(id,value1):
        value1=round((180-value1)*11.375)
        print(value1)
        if(value1>=Actuate.DXL_MINIMUM_POSITION_VALUE and value1<=Actuate.DXL_MAXIMUM_POSITION_VALUE):
            dxl_comm_result, dxl_error = Actuate.packetHandler.write4ByteTxRx(Actuate.portHandler, id,Actuate.ADDR_GOAL_POSITION, value1)
            if dxl_comm_result != COMM_SUCCESS: 	
                print("%s" % Actuate.packetHandler.getTxRxResult(dxl_comm_result))
            elif dxl_error != 0:
                print("%s" % Actuate.packetHandler.getRxPacketError(dxl_error))
            
            dxl_present_position, dxl_comm_result, dxl_error = Actuate.packetHandler.read4ByteTxRx(Actuate.portHandler, id, Actuate.ADDR_PRESENT_POSITION)
            print("[ID:%03d] GoalPos:%03d  PresPos:%03d" % (Actuate.DXL_ID0, value1, dxl_present_position))
            return dxl_present_position
            print()
        else:
            print("Values out of range")

    def disable_torque(id):
        dxl_comm_result, dxl_error = Actuate.packetHandler.write1ByteTxRx(Actuate.portHandler, id, Actuate.ADDR_TORQUE_ENABLE, Actuate.TORQUE_DISABLE)
        if dxl_comm_result != COMM_SUCCESS:
            print("%s" % Actuate.packetHandler.getTxRxResult(dxl_comm_result))
        elif dxl_error != 0:
            print("%s" % Actuate.packetHandler.getRxPacketError(dxl_error))
        print("Torque has been disabled for Motor ID: ",id)
    
    def Disable_all_Motors():
        print("Recieved request to disable all motors...")
        for disable_all in range (3):
            Actuate.disable_torque(disable_all) 
            print("Disabling Motor ID: ",disable_all)
        print("All Motors Disabled !!!")

    def Enable_all_Motors():
        print("Recieved request to enable all motors...")
        for activate_motors in range(1,4):
            print("Enabling torque for Dynamixel Motor ID: ",activate_motors)
            Actuate.enable_torque(activate_motors)
            print("Enabling velocity for Dynamixel Motor ID: ",activate_motors)
            Actuate.enable_velocity(activate_motors)


    def present_position(id):
        dxl_present_position, dxl_comm_result, dxl_error = Actuate.packetHandler.read4ByteTxRx(Actuate.portHandler, id, Actuate.ADDR_PRESENT_POSITION)
        return dxl_present_position   





act=Actuate()

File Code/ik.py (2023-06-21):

import Actuator
from Actuator import Actuate
import math
import Socket
import threading
# import Main

e  =  35.0
f  =  140.0
re =  340.0
rf =  160.0

# Trigonometric constants
s      = 165*2
sqrt3  = math.sqrt(3.0)
pi     = 3.141592653
sin120 = sqrt3 / 2.0
cos120 = -0.5
tan60  = sqrt3
sin30  = 0.5
tan30  = 1.0 / sqrt3

class kinematics():

    # Forward kinematics: (theta1, theta2, theta3) -> (x0, y0, z0)
    #   Returned {error code,theta1,theta2,theta3}
    def forward(theta1, theta2, theta3):
        x0 = 0.0
        y0 = 0.0
        z0 = 0.0
        
        t = (f-e) * tan30 / 2.0
        dtr = math.pi / 180.0
        
        theta1 *= dtr
        theta2 *= dtr
        theta3 *= dtr
        
        y1 = -(t + rf*math.cos(theta1) )
        z1 = -rf * math.sin(theta1)
        
        y2 = (t + rf*math.cos(theta2)) * sin30
        x2 = y2 * tan60
        z2 = -rf * math.sin(theta2)
        
        y3 = (t + rf*math.cos(theta3)) * sin30
        x3 = -y3 * tan60
        z3 = -rf * math.sin(theta3)
        
        dnm = (y2-y1)*x3 - (y3-y1)*x2
        
        w1 = y1*y1 + z1*z1
        w2 = x2*x2 + y2*y2 + z2*z2
        w3 = x3*x3 + y3*y3 + z3*z3
        
        # x = (a1*z + b1)/dnm
        a1 = (z2-z1)*(y3-y1) - (z3-z1)*(y2-y1)
        b1= -( (w2-w1)*(y3-y1) - (w3-w1)*(y2-y1) ) / 2.0
        
        # y = (a2*z + b2)/dnm
        a2 = -(z2-z1)*x3 + (z3-z1)*x2
        b2 = ( (w2-w1)*x3 - (w3-w1)*x2) / 2.0
        
        # a*z^2 + b*z + c = 0
        a = a1*a1 + a2*a2 + dnm*dnm
        b = 2.0 * (a1*b1 + a2*(b2 - y1*dnm) - z1*dnm*dnm)
        c = (b2 - y1*dnm)*(b2 - y1*dnm) + b1*b1 + dnm*dnm*(z1*z1 - re*re)
        
        # discriminant
        d = b*b - 4.0*a*c
        if d < 0.0:
            return [1,0,0,0] # non-existing povar. return error,x,y,z
        
        z0 = -0.5*(b + math.sqrt(d)) / a
        x0 = (a1*z0 + b1) / dnm
        y0 = (a2*z0 + b2) / dnm

        return [0,x0,y0,z0]

    # Inverse kinematics
    # Helper functions, calculates angle theta1 (for YZ-pane)
    def angle_yz(x0, y0, z0, theta=None):
        y1 = -0.5*0.57735*f # f/2 * tg 30
        y0 -= 0.5*0.57735*e # shift center to edge
        # z = a + b*y
        a = (x0*x0 + y0*y0 + z0*z0 + rf*rf - re*re - y1*y1) / (2.0*z0)
        b = (y1-y0) / z0

        # discriminant
        d = -(a + b*y1)*(a + b*y1) + rf*(b*b*rf + rf)
        if d<0:
            return [1,0] # non-existing povar.  return error, theta

        yj = (y1 - a*b - math.sqrt(d)) / (b*b + 1) # choosing outer povar
        zj = a + b*yj
        theta = math.atan(-zj / (y1-yj)) * 180.0 / pi + (180.0 if yj>y1 else 0.0)
        
        return [0,theta] # return error, theta

    def inverse(x0, y0, z0):
        theta1 = 0
        theta2 = 0
        theta3 = 0
        status = kinematics.angle_yz(x0,y0,z0)

        if status[0] == 0:
            theta1 = status[1]
            status = kinematics.angle_yz(x0*cos120 + y0*sin120,
                                    y0*cos120-x0*sin120,
                                    z0,
                                    theta2)
        if status[0] == 0:
            theta2 = status[1]
            status = kinematics.angle_yz(x0*cos120 - y0*sin120,
                                    y0*cos120 + x0*sin120,
                                    z0,
                                    theta3)
        theta3 = status[1]

        return [status[0],theta1,theta2,theta3]
    
    def convert_deg_to_steps(deg):
        steps=deg
        for i in range(1,4):
            steps[i]=round((180-steps[i])*11.375)
            print(steps[i])
        return steps
# value=120
    def Actuate_to_position(Coordinates):
        req_position=0
        deg=kinematics.inverse(Coordinates[0],Coordinates[1],Coordinates[2])
        if deg[0]==0:
            print("Degrees before conversion: ",deg)
            Actuator.Current_Deg=deg
            print("Actuator Current Degree: ",Actuator.Current_Deg)
            for send_index in range(4):
                Socket.send_angles[send_index]=(Actuator.Current_Deg[send_index]*(pi/180))
            print("send angles: ",Socket.send_angles)
            print("Degrees after inverse: ",deg)
            for req_position in range(3):
                Actuate.actuate_motors(req_position,deg[req_position+1])
        else:
            print("\nError during inverse kinematic calculation (of angles)\nfor coordinates: ",Coordinates[0],Coordinates[1],Coordinates[2])
    
# pos=kinematics.forward(60,37,54)
# print("Error Code: ",pos[0])
# print("Position 1: ",pos[1])
# print("Position 2: ",pos[2])
# print("Position 3: ",pos[3])
# x-axis max is 170
# z-axis max is 281
# deg=kinematics.inverse(0,0,-281)
# print("Error Code: ",deg[0])
# print("Angle 1:",deg[1])
# print("Angle 2:",deg[2])
# print("Angle 3:",deg[3])
# for simulink model where sagging=0 deg=90-deg
# # for 0 degree step count is 2048
# # deg=[0,-2,-2,-2]
# steps=kinematics.convert_deg_to_steps(deg)
# print(steps)

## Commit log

2023-02-21 Update
    Reference material
2023-03-16 UML diagrams and references
    [table_9.3.xlsx]
2023-03-20 tracebility Matrix
2023-03-29 Simulink model
    pre-build attempt at executing function flow in simulink
2023-03-31 Inspect and calibrate functions updated
2023-06-19 update 190623
    [1.SLDPRT, DELTA_ROBOT.SLDASM, Delta2.SLDASM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]
